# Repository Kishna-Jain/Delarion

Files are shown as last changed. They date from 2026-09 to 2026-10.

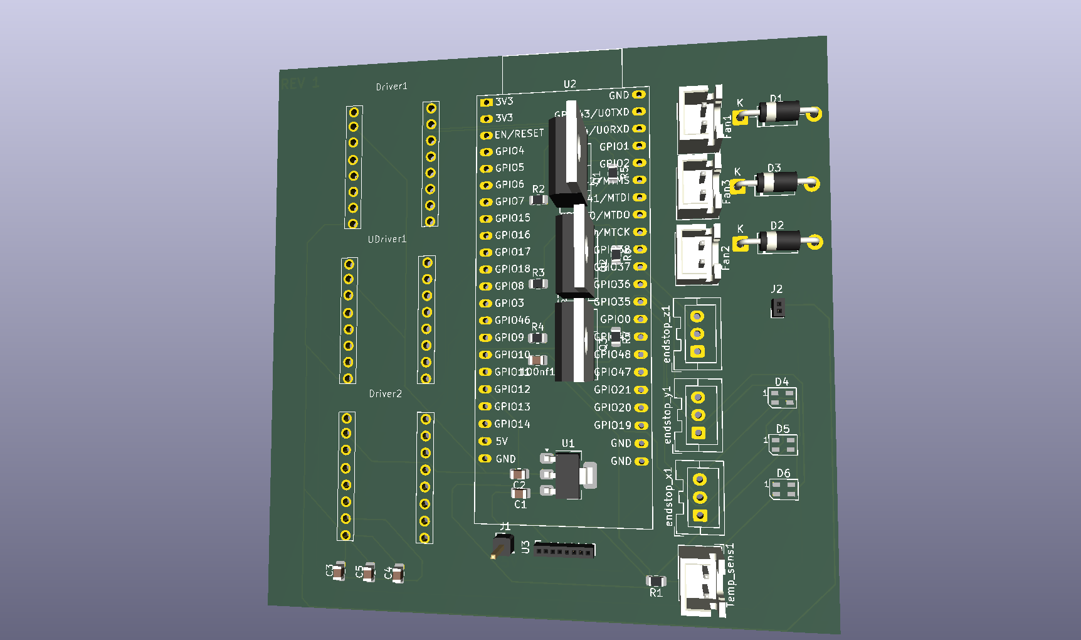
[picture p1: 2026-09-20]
Klipper_mcu.png

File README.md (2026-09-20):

# Delarion
A custom core XY 3d printer

Delarion is a project aimed to make a decent bang for your buck core xy 3d printer. The frame is made out of 2020 aluminum extrusions giving it a sturdy rigid frame with ball screws,linear rails to provide that buttery smooth movement.



How it began? basically every geek has an urge to keep building random nerd stuff via youtube tutorial, i went via it through but gotta admit the work-around required to make something without a 3d printer that uses is quite messy with the final thing not having that finesse instead a messy encasement made out of scraps, i guess we all been there. When i went out to buy a cheap 3d printer the results werent that good. Yes 3d printers are nowadays quite cheap starting from a 100 bucks usd but honestly thoose are mostly crap and why to even buy an ender 3 nowadays as everything is just better than it. Yes bamboo is an option some budget products are there but still not satisfactory. So a good printer will cost about 500 dollars while cheap ones are just cheap(Atleast over here in my area) So the quest beagn to create a 3d printer and voila that how this project began.

Key takaways:
Delarion utilizes Klipper firmware with tmc2208 drivers,nema17 stepper motors. The main MCU is an esp32 s3, which does provide endless possibilities for trying out diff stuff. The mian idea for klipper rather than some other mcu based firmware is that 1) it utilizes microprocessor so yeah huge speed advantage, 2) everyone has an old laptop or a raspberry pi laying round, 3) Documentaion

PCB:
its a really basic custom pcb, which includes an MPU6050, tmc2208 drivers, Note that you will need to provide the appropriate 24volts clean supply to the board, 5v supply is cleanly regulated by an ams117. And yeah IRLZ44N needs to be attached at the bottom of the board not the top.

Klipper_mcu
This is the first PCB i made so yeah not beautiful, not well laid out, but yeah it works 100% or thats what i atleast hope for

3d model Demo link::
https://cad.onshape.com/documents/ddc5642abc531e1225c0dc8b/w/1fb68ecf66842d529f7141f3/e/0a949859a3af9baaf41af0a4

CREDITS:
@hacktheclub honetly this project was only possible cause of them, they helped me connect find the right people and finally pushed me to make my dream.

@Stardance as per this commit i am submitting it for funding, fingers crossed that i get funded to make it actual project kudos

@RaygunRupe at first i just started to make it blindly, buy stuff build it and figure on the fly, the only reason i am actually stuck in this deep at designing, to polish the looks is cause of this mf, otherwise i would had already made a mess by skipping all the design aan CAD stuff

@Mistsu Makes(youtube) I waatched his toutorial to understand how to do this project, how the motion system works how the bedslinging mechanism should, if it werent for him, it would had been quite more difficult. And yeah it was this dude only whoose video after watching i decided that yeah lets fing do it, he was my starting point kinda that yeah i can too make this.

@ 3ddistributed.com This gottna be the best website to understand coreXY working, i watched countless toutorials but in the end got how to do this vis this website's infographics only

@Slack hardware community, thoose guys also helped me a lot from figring out how this shit works to networking with people that helped me make this

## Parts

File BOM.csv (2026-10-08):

USD per INR rate (editable): |  | 95.90 | .
Item Description | Quantity | Price (INR) per unit (approx) | Total Price (INR) | Total Price (USD) | Supplier
Ballscrew (300mm with end machining) | 2 | 2,730.00 | 5,460.00 | $56.93 | https://robokits.co.in/mechanical-parts/ball-screw-accessories/astro-ball-screw-rod-1204-12mm-dia.-of-500mm-length-with-end-machining-with-sfu1204-flange-nut-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
MGN12H Linear Rail guides | 3 | 550.00 | 1,650.00 | $17.21 | https://robu.in/product/mgn12h-sliding-block/
MGN12H Linear Rails(1m) | 1 | 2,550.00 | 6,900.00 | $71.95 | https://robu.in/product/mgn12h-linear-guide-rail-1m-2/
GT2 Timing Pulley (20 Teeth) | 4 | 70.00 | 280.00 | $2.92 | https://robu.in/product/aluminum-gt2-timing-pulley-for-6mm-belt-20-tooth-5mm-bore-2pcs/
GT2 Open Timing Belt (6mm width) | 1 | 66.90 | 669.00 | $6.98 | https://robu.in/product/10m-gt2-width-6mm-white-open-timing-belt-for-3d-printer/
GT2 Timing Idler Pulleys | 4 | 130.00 | 520.00 | $5.42 | https://robu.in/product/aluminum-gt2-timing-pulley-6mm-belt-16-tooth-5mm-bore-2pcs/
NEMA 17 Stepper Motors (D-Type Shaft) | 4 | 1,329.00 | 5,316.00 | $55.43 | https://robu.in/product/stepperonline-nema-17-bipolar-stepper-motor-26ncm/
2020 V-Slot Aluminum Extrusion Profiles (1M lengths) | 4 | 460.00 | 1,840.00 | $19.19 | https://robu.in/product/easymech-20x20-t-slot-aluminium-extrusion-profile-1000-mm/
T-Shape Corner Bracket Plates for 2020 | 4 | 525.00 | 2,100.00 | $21.90 | Local
Ball Screw End Support Bearings (BK/BF12) | 2 | 630.00 | 1,260.00 | $13.14 | Local
NEMA 17 Stepper Motor Mounting Brackets | 2 | 422.00 | 844.00 | $8.80 | Local
2020 Cast Corner Brackets | 24 | 62.75 | 1,506.00 | $15.70 | Local
M5 Hammer / Sliding Nuts | 100 | 9.00 | 900.00 | $9.38 | https://onlyscrews.in/products/m4-profile-nuts-mild-steel-with-nickel-plating-for-3030-series-t-nut-hammer-nut-1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
M3 Hammer / Sliding Nuts | 15 | 8.50 | 132.50 | $1.38 | https://onlyscrews.in/products/m3-profile-nuts-mild-steel-with-nickel-plating-for-2020-series-t-nut-hammer-nut
M5 Button Head Screws (8mm, 13mm, 16mm, 20mm mix) | 80 | 3.29 | 263.00 | $2.74 | Local
M5 T-Nuts | 20 | 28.90 | 578.00 | $6.03 | https://robu.in/product/easymech-sliding-m5-t-nut-for-20x20-aluminium-profile-10-pcs/
M3 Screws (12mm) | 16 | 3.31 | 53.00 | $0.55 | Local
3D Printed Custom Parts | 1 | 1,050.00 | 1,050.00 | $10.95 | Local
100nf Capacitor (C_0805) | 1 | 5.25 | 5.25 | $0.05 | Local
10uf Capacitor (C_0805) [C1, C2] | 2 | 5.25 | 10.50 | $0.11 | Local
100uf Capacitor (C_0805) [C3, C4, C5] | 3 | 7.35 | 22.05 | $0.23 | Local
1N4007 Diode [D1, D2, D3] | 3 | 21.30 | 63.90 | $0.67 | https://www.digikey.in/en/products/detail/onsemi/1N4007RLG/918021
SK6805 LED [D4, D5, D6] | 3 | 14.70 | 44.10 | $0.46 | Local
TMC2208/2209 Stepper Driver (Driver1) | 1 | 512.00 | 512.00 | $5.34 | https://robu.in/product/tmc2209-stepper-motor-driver/
TMC2208/2209 Stepper Driver (Driver2, UDriver1) | 2 | 512.00 | 1,024.00 | $10.68 | https://robu.in/product/tmc2209-stepper-motor-driver/
JST 3-Pin Socket Connector [Endstops] | 3 | 10.50 | 31.50 | $0.33 | Local
JST 2-Pin Pin Connector [Fans 1-3] | 3 | 10.50 | 31.50 | $0.33 | Local
Pin Header 1x01 Socket [J1] | 1 | 10.50 | 10.50 | $0.11 | Local
Pin Socket 1x02 [J2] | 1 | 10.50 | 10.50 | $0.11 | Local
IRLZ44N MOSFET [Q1, Q2, Q3] | 3 | 42.00 | 126.00 | $1.31 | https://robu.in/product/irlz44n/
4.7k ohm Resistor (R1) | 1 | 5.25 | 5.25 | $0.05 | Local
220 ohm Resistor (R2) | 1 | 5.25 | 5.25 | $0.05 | Local
220 ohm Resistor [R3, R4] | 2 | 5.25 | 10.50 | $0.11 | Local
10k Resistor [R5, R6, R7] | 3 | 5.25 | 15.75 | $0.16 | Local
JST 2-Pin Connector [Temp Sensor] | 1 | 10.50 | 10.50 | $0.11 | Local
AMS1117-3.3 Voltage Regulator [U1] | 1 | 11.55 | 11.55 | $0.12 | Local
ESP32-S3-DevKitC [U2] | 1 | 882.00 | 1,839.00 | $19.18 | https://robu.in/product/esp32-wroom-e-esp32-devkitc-core-board-for-arduino/
MPU6050 Accelerometer [U3] | 1 | 157.50 | 157.50 | $1.64 | https://robu.in/product/mpu-6050-gyro-sensor-2-accelerometer/
extruder | 1 | 1,170.00 | 1,170.00 | $12.20 | https://www.amazon.in/dp/B07TVP1Q33
Heat Bed | 1 | 2,915.00 | 2,915.00 | $30.40 | https://www.amazon.in/dp/B0HH76B4YJ
Hot End | 1 | 849.00 | 849.00 | $8.85 | https://www.amazon.in/dp/B07L8ZGYVF
Springs | 2 | 219.00 | 438.00 | $4.57 | https://www.amazon.in/dp/B07SQCC24P
SMPS | 1 | 1,399.00 | 1,399.00 | $14.59 | https://www.amazon.in/dp/B07LCVY4Q3
PCB | 1 | 800.00 | 800.00 | $8.34 | https://robu.in
Step Down Converter [XL103] | 1 | 84.00 | 84.00 | $0.88 | Local
 |  | Total price | 42,923.60 | $447.59

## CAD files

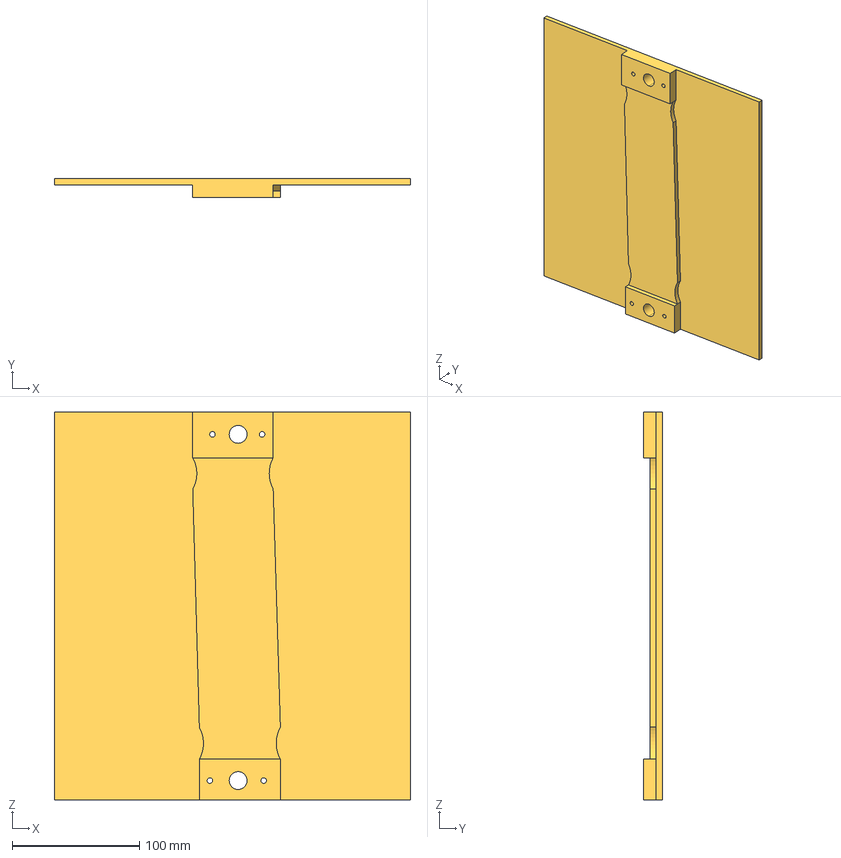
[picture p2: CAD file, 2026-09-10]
3D printed files/Part Studio 1 - Part 14.step
280.0 x 15.0 x 305.0 mm

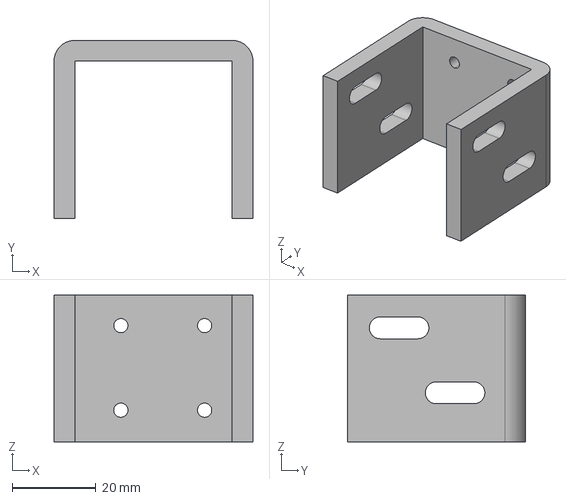
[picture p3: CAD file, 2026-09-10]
3D printed files/Part Studio 1 - Part 8.step
47.5 x 42.6 x 35.0 mm

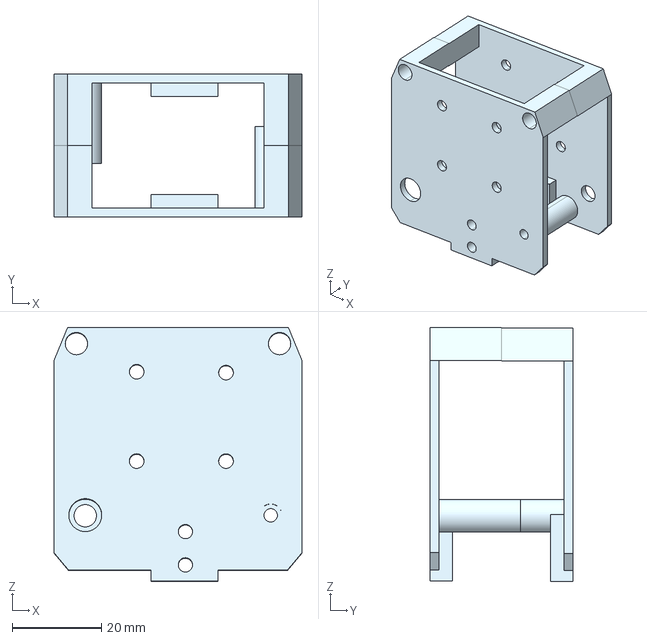
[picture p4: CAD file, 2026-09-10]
3D printed files/Part Studio 1 - Part 6.step
55.5 x 32.0 x 56.9 mm

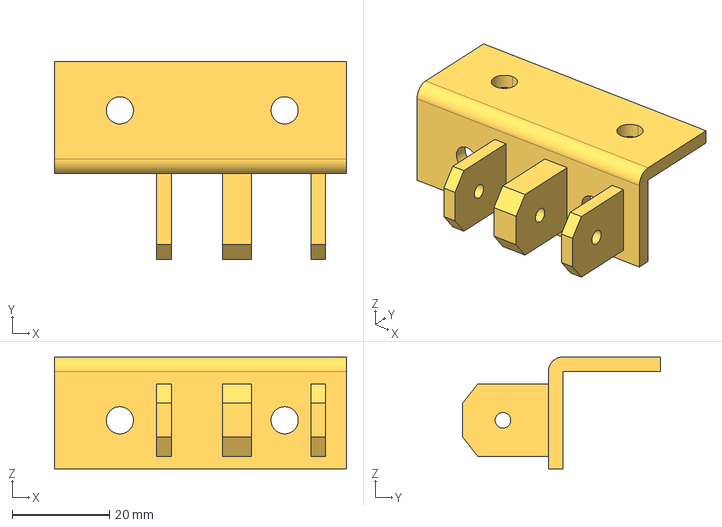
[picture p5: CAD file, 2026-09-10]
3D printed files/Part Studio 1 - Part 9.step
60.0 x 40.6 x 23.0 mm

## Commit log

2026-09-10 Update README to reflect core XY 3D printer details
    Expanded project description and clarified printer type.
2026-09-20 Update README with project details and key takeaways
    Expanded project description and added key takeaways about Delarion's components and PCB requirements.
2026-09-20 Update PCB section with additional details
    Added information about IRLZ44N placement and a demo link.
2026-09-27 Fix NEMA 17 Stepper Motors price in BOM
    Updated NEMA 17 Stepper Motors price from 3238 to 723.
    [3d_printer_complete_bom.csv]
2026-10-08 Add new temporary file in 3D printed files directory
2026-10-08 Update and rename tenp to PCB readme
2026-10-08 Update BOM.csv with new item entries and prices
    [BOM.csv]
2026-10-21 Remove Bill of Materials section from README
    Removed the Bill of Materials section and its details from the README.
2026-10-21 Add example config file for corexy printer
    This file contains configuration settings for a corexy printer, including parameters for steppers, extruder, heater bed, fan, and printer settings.
2026-10-21 Rename Klipper settings to Klipper config
2026-10-21 Update Klipper config
2026-10-21 Add initial Klipper firmware configuration
    Added initial configuration for Klipper firmware.
2026-10-25 Revise PCB README for thermal management details
    Updated PCB README to clarify thermal issues and cooling requirements.
